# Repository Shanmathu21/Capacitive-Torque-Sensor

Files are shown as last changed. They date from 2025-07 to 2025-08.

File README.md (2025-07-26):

# Capacitive Torque Sensor Project

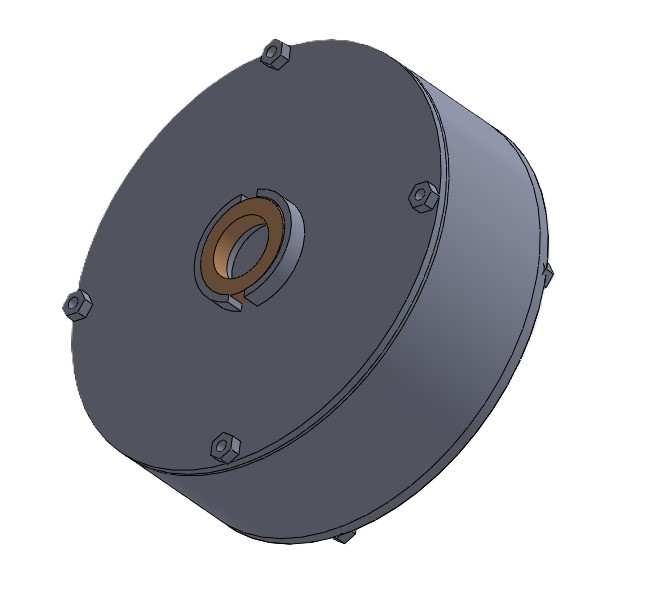
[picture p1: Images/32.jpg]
Product Overview


Welcome to the official repository for our **Capacitive Torque Sensor** – a novel torque sensing solution designed for precision, compactness, and cost-effectiveness. This repository contains all design files, documentation, and resources used in the development of our sensor system.

## 📂 What’s Inside?

This repo includes:

- ✅ **CAD Designs** (SolidWorks): 3D models for the sensor structure.
- ✅ **PCB Schematics** (Altium): Custom-designed electronics for sensing.
- ✅ **Firmware Code**: Interface microcontroller with CDC and output handler.
- ✅ **Documentation**:
  - Full Design Report
  - Production & Assembly Guidelines
  - User Manual
- ✅ **Images**: CAD visualizations, PCB renders, and actual prototype internals.

---

## 🛠️ Project Summary

Our system measures torque through **capacitive sensing technology**, leveraging the deformation of sensor plates to detect torque-induced changes in capacitance.

**Core Components:**

- **Sensor Design**: Custom plate layout for deflection measurement.
- **Capacitance-to-Digital Converter**: Using *PCAP04 CDC* for accurate sensing.
- **Microcontroller Interface**: *ATmega16U4/32U4* for data processing and USB communication.
- **Visualization**: Real-time torque output via display and PC interface.
- **Mechanical Housing**: Designed with precision for durability and alignment.

---

## 👥 Team & Collaboration

This project was accomplished by a passionate group of **8 dedicated undergraduate engineers** from the University of Moratuwa. Over weeks of brainstorming, prototyping, testing, and redesigning, we gave our full effort to bring this innovation to life.

---

## 📸 Highlights from the Build

### 1. Actual Final Product
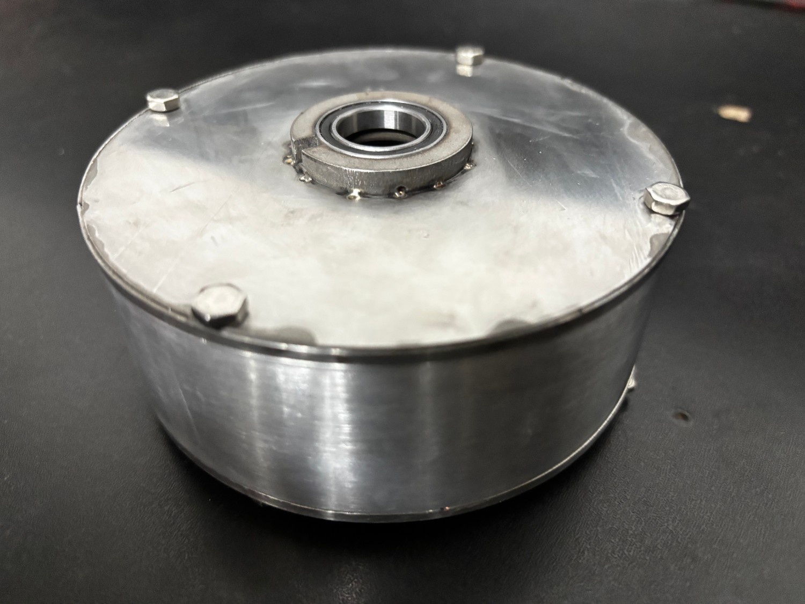
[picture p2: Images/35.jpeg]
CAD Design


### 2. Custom PCB
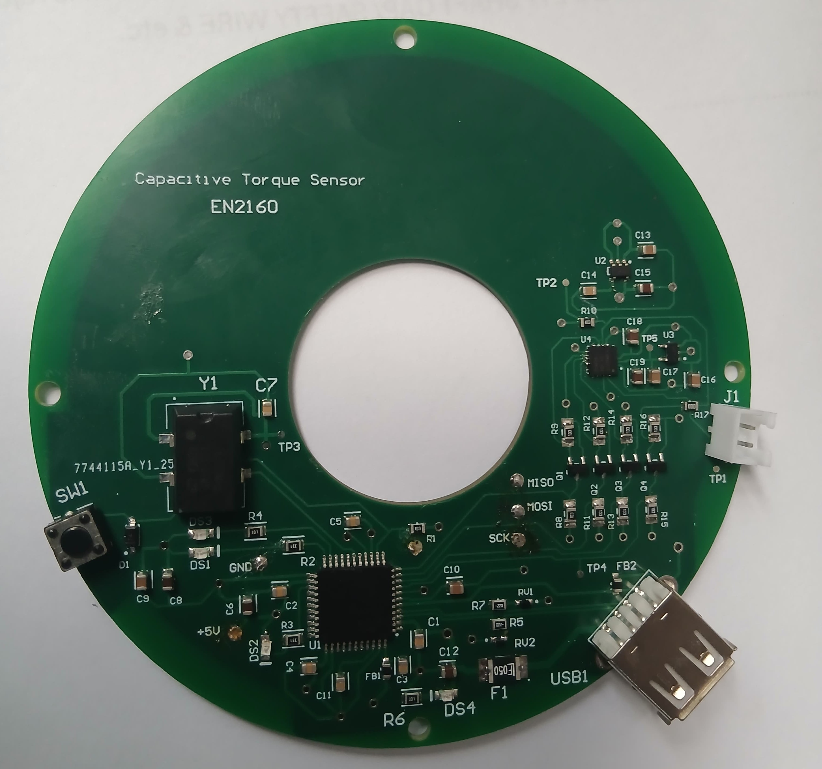
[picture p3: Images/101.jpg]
PCB Layout


### 3. Internal View of Sensor
Internal View

### 4. Exploded View
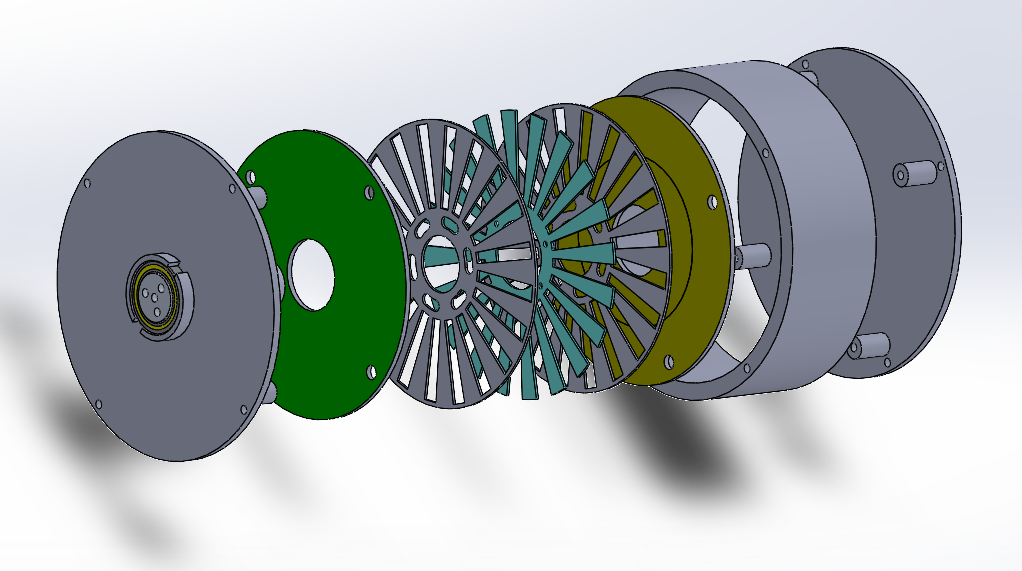
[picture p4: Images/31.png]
Exploded View


---

## 📌 Final Note

While we couldn't get a fully working sensor in the end, we achieved nearly **80% of our goal**. Our team poured countless hours into designing, simulating, assembling, coding, debugging, and refining this sensor. The journey taught us more than just engineering—it taught us perseverance, teamwork, and the power of iterative improvement.

> “Hard work doesn't always guarantee success, but it always guarantees growth.”

---

🧠 Thank you for checking out our work. Feedback and suggestions are warmly welcome!

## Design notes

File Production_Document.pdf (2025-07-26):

# Production Document

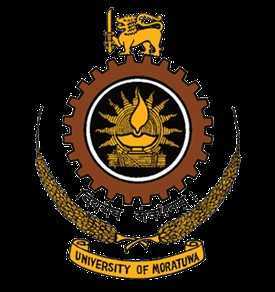
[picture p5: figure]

### Department of Electronic and Telecommunication Engineering

### University of Moratuwa

# Capacitive Torque Sensor

## Group Members:

## De Zoysa.A.S.I - 220106D Dayananthan.T - 220096T Mathujan.S - 220389U Pirathishanth.A - 220480P Jeyasekara.S.P.R - 220257N Sulojan.R - 220626V Ananthakumar.T - 220029T Ahilakumaran.T - 220017F

## 1 Objective

The objective of this production report is to document the development, manufacturing process, and performance evaluation of the Capacitive Torque Sensor. This report aims to provide a comprehensive overview of the sensor’s design, production stages, quality control measures, and testing results to ensure it meets the required specifications for accuracy, sensitivity, and durability. Additionally, this report serves as a reference for stakeholders, facilitating future improvements, scalability, and compliance with industry standards. By detailing key challenges, solutions, and production efficiencies, this document supports continuous optimization and successful deployment of the torque sensor in its intended applications.

## 2 System Overview

### 2.1 Working Principle

When torque (τ ) is applied to the shaft, it induces a proportional angular deflection (θ) along the axis, governed by:

τ = G · J ·

θ
L

(1)

where G is the shear modulus, J the polar moment of inertia, and L the shaft length.

### 2.1.1 Capacitance Variation Mechanism

The angular deflection alters the overlapping area (A) between two parallel conductive plates separated by a dielectric (e.g., polyimide film). The capacitance (C) is given by:

C = ε0εr

A
d

(2)

where ε0 is vacuum permittivity, εr the dielectric constant, and d the plate separation. Area Modulation: Radial plate geometry maximizes sensitivity to angular displacement.

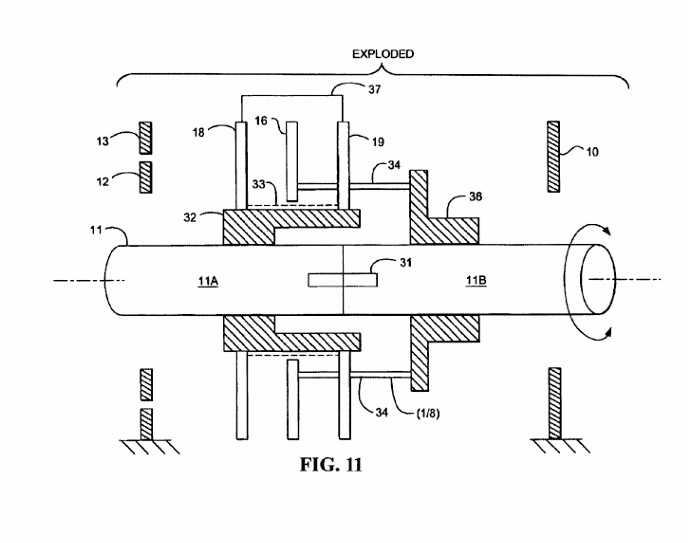
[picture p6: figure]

Figure 1: Internal Arrangement of the Sensor

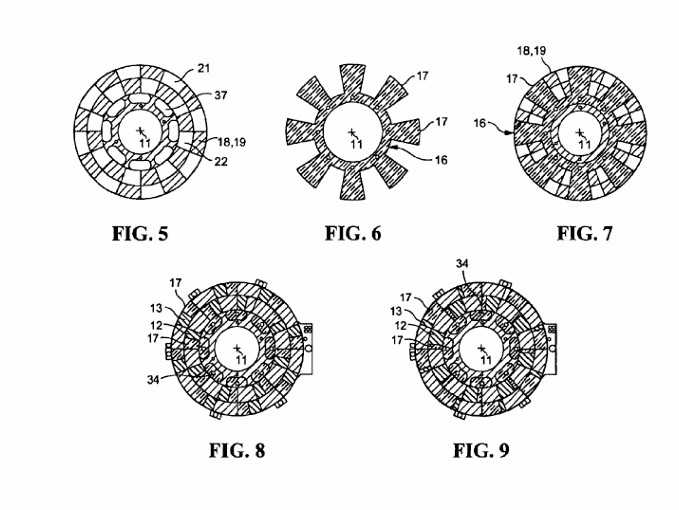
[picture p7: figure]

Figure 2: Area modulation in the capacitance measurement

### 2.1.2 Signal Processing Chain

- Capacitance-to-Digital Converter (PCAP04):

– 24-bit resolution for ±0.1 fF sensitivity

– Integrated temperature compensation

– SPI interface for microcontroller communication

- Microcontroller (ATmega32U):

– Linearizes data using polynomial calibration curves

– Outputs data via USB at 1 kSPS

### 2.2 Block Diagram

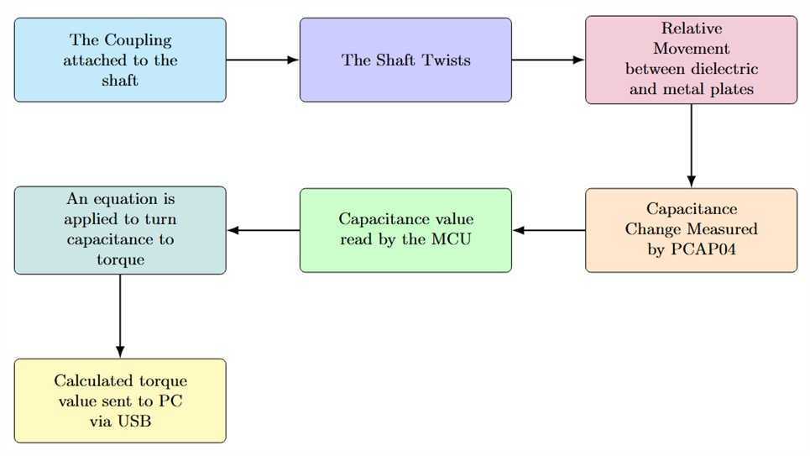
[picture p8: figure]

Figure 3: Block diagram of the system

## 3 Mechanical Design

The mechanical design of the capacitive torque sensor consists of two primary components: the enclosure, which provides robust protection and structural integrity, and the internal structure, which houses the sensitive capacitive elements and ensures precise torque measurement.

### 3.1 Enclosure Overview

The enclosure is constructed from anodized aluminum to provide corrosion resistance and electromagnetic shielding. Its design includes mounting flanges for secure attachment to rotating shafts, and it houses the capacitive sensing elements while maintaining environmental protection.

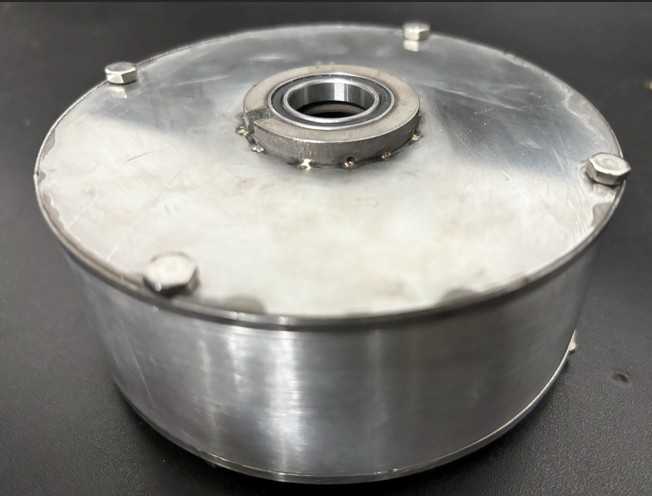
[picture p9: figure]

Figure 4: Enclosure of the Sensor

### 3.1.1 Parts of the enclosure

The enclosure consists of a middle body, 2 outer lids and 2 bearings.

### 3.2 Internal structure Overview

Internal mechanism of the sensor consists of a shaft,2 metal disks, 1 dielectric disk, holders of the disks.

### 3.2.1 Assembly of Internals

1. Begin by attaching the first metal disk to the holder.
2. Place the dielectric disk over the first metal disk, ensuring proper alignment.

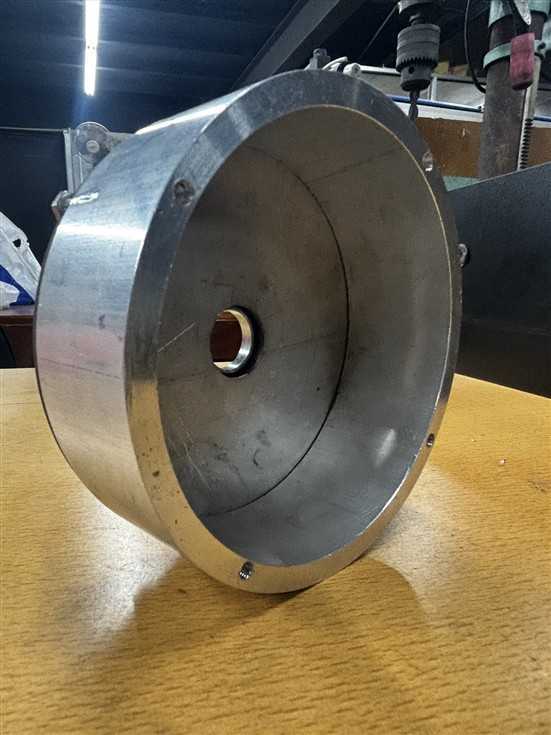
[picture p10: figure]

Figure 5: Middle part of the enclosure made of aluminium

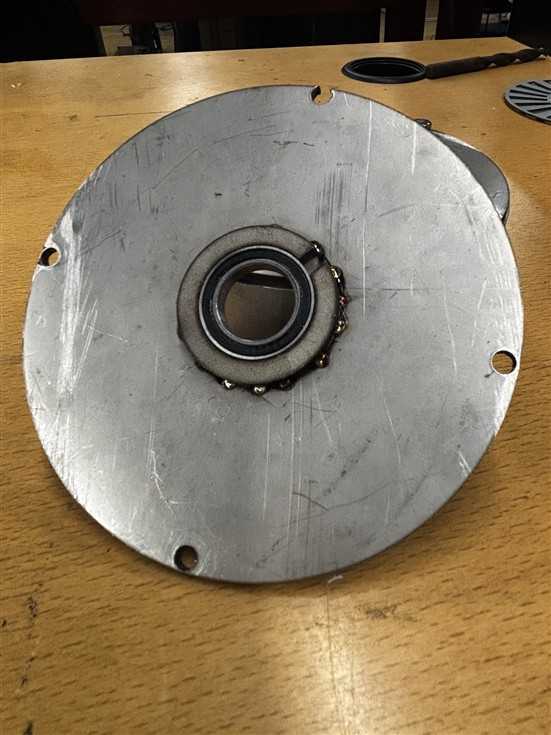
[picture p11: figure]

Figure 6: Outer lids of the sensor made of steel.

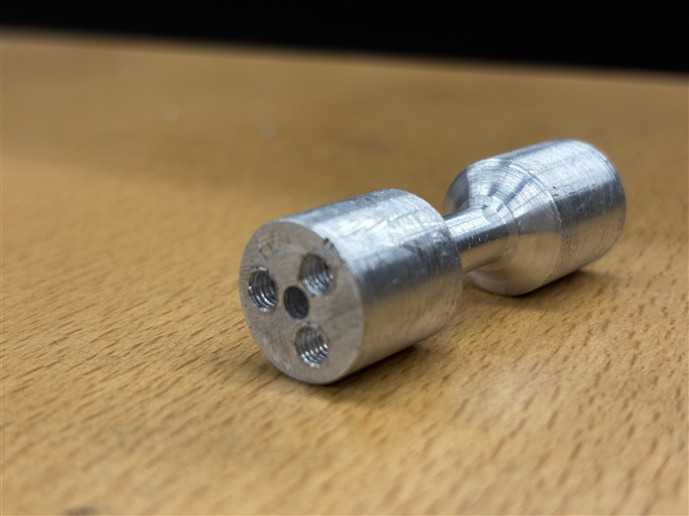
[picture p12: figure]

Figure 7: Aluminium shaft machined using a lathe.

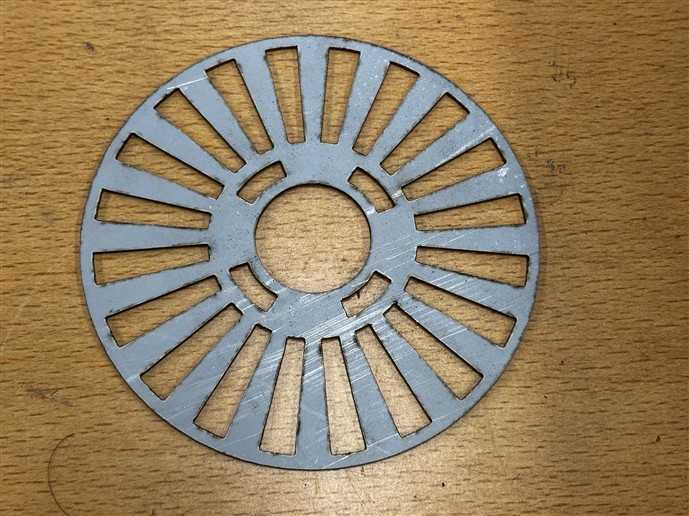
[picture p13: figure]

Figure 8: Metal disks made of nickel-coated steel, cut using CNC machining

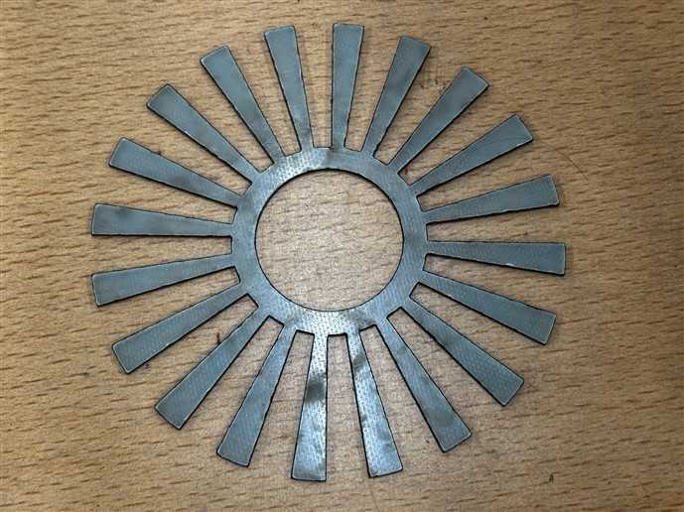
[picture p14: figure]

Figure 9: Dielectric disk cut using laser cutting.

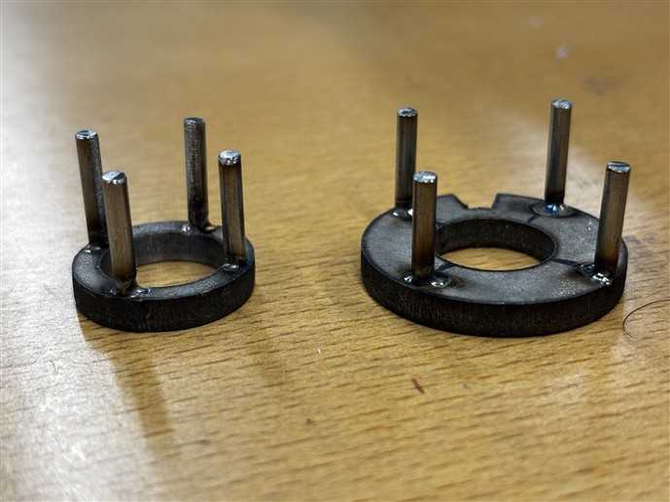
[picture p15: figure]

Figure 10: Holders that connect metal and dielectric disks to the shaft.

3. Attach the second metal disk on top of the dielectric disk using the same holder.
4. Secure the assembled holder to the shaft.
5. assemble the dielectric with the second holder.
6. Attach the second holder to the shaft.
7. Finally, mount the shaft onto the bearings to complete the assembly.

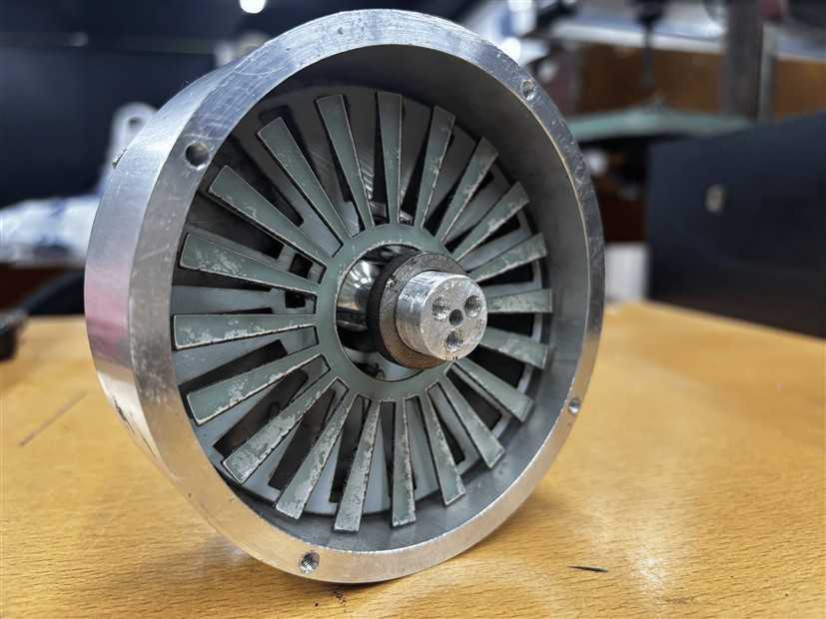
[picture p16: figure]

Figure 11: Complete internal assembly.

## 4 Schematic Circuit Design

### 4.1 MCU Circuit

– Core Components:
∗ ATmega32U4 microcontroller
∗ Key functions:
- Reads capacitance via SPI
- Computes torque using calibration equation
- Manages USB communication

– Power Management:
∗ 5x VCC pins with decoupling capacitors
∗ AVCC pin filtered via ferrite bead

– Clock: ECS-8FMX-160-TR 16MHz oscillator for USB timing

– UI: Reset button, 3x LEDs (USB/SPI/status)

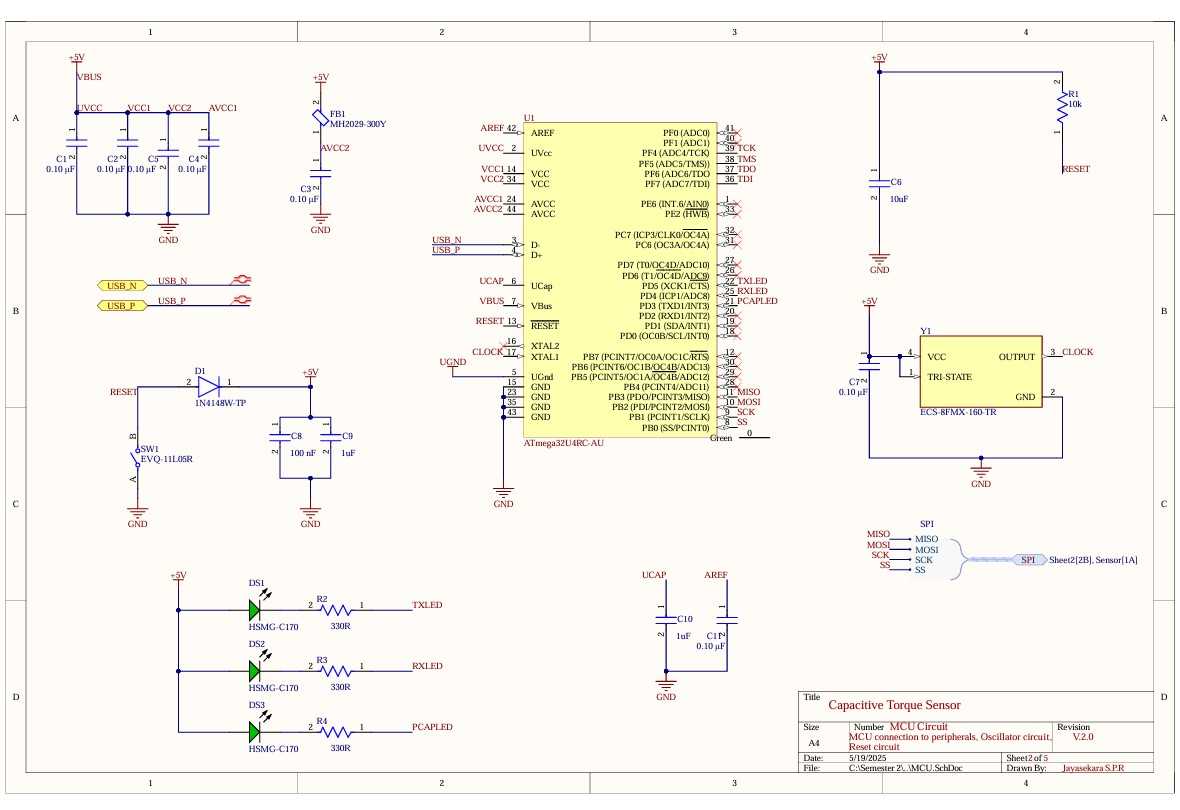
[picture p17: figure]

Figure 12: MCU Schematic

### 4.2 USB Circuit

– Provides data transmission and power supply (+5V via VBUS).

– ESD Protection:
∗ +D/-D lines connected to ground through varistors.

– Grounding:
∗ USB ground (UGND) and main ground linked via ferrite bead for:
- High-frequency noise filtering
- Prevention of ground loops

– Power Line Protection:
∗ Resettable fuse for overcurrent protection ∗ Capacitor C12 for ripple smoothing
∗ LED DS4 as power indicator

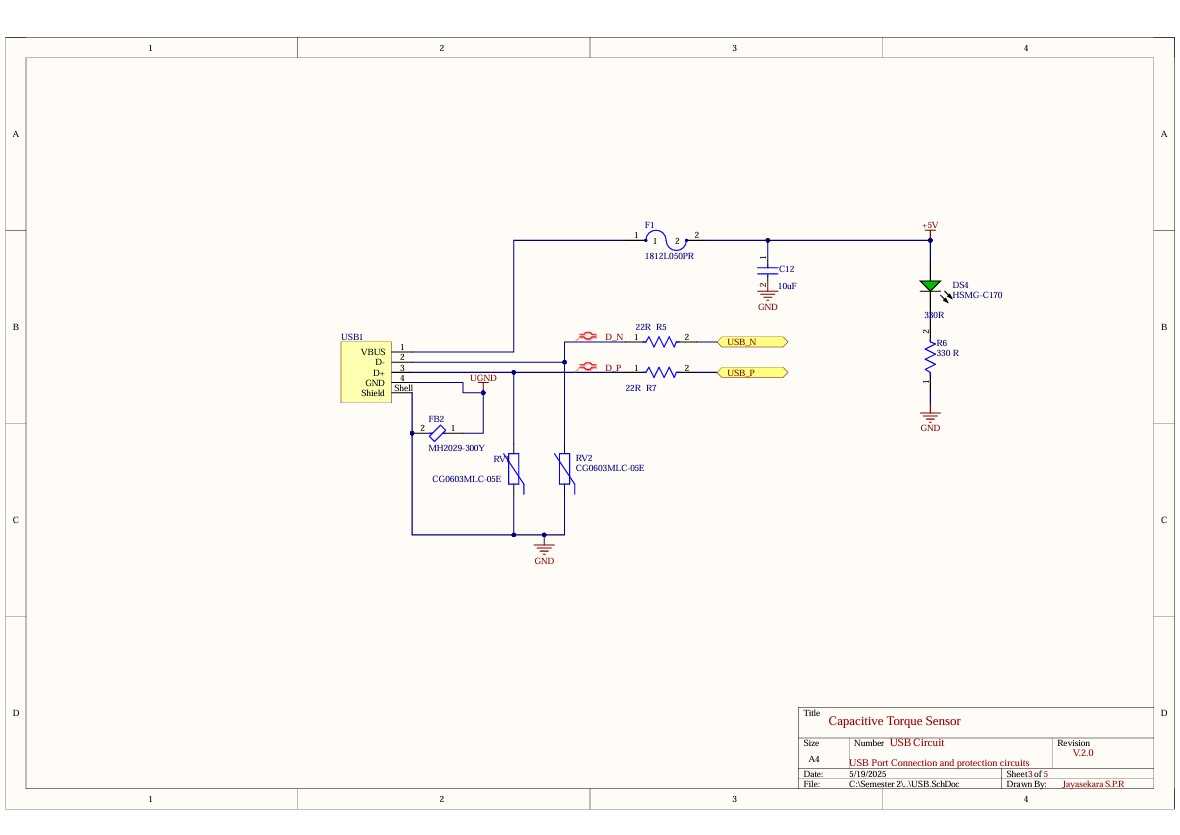
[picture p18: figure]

Figure 13: USB Schematic

### 4.3 Power Circuit

– Generates regulated voltages:
∗ +3.3V and +1.8V for PCAP04 CDC

– Design Features:
∗ Enable pins tied to VCC for continuous operation ∗ Input/output capacitors for:
- High-frequency noise filtering
- Ripple reduction

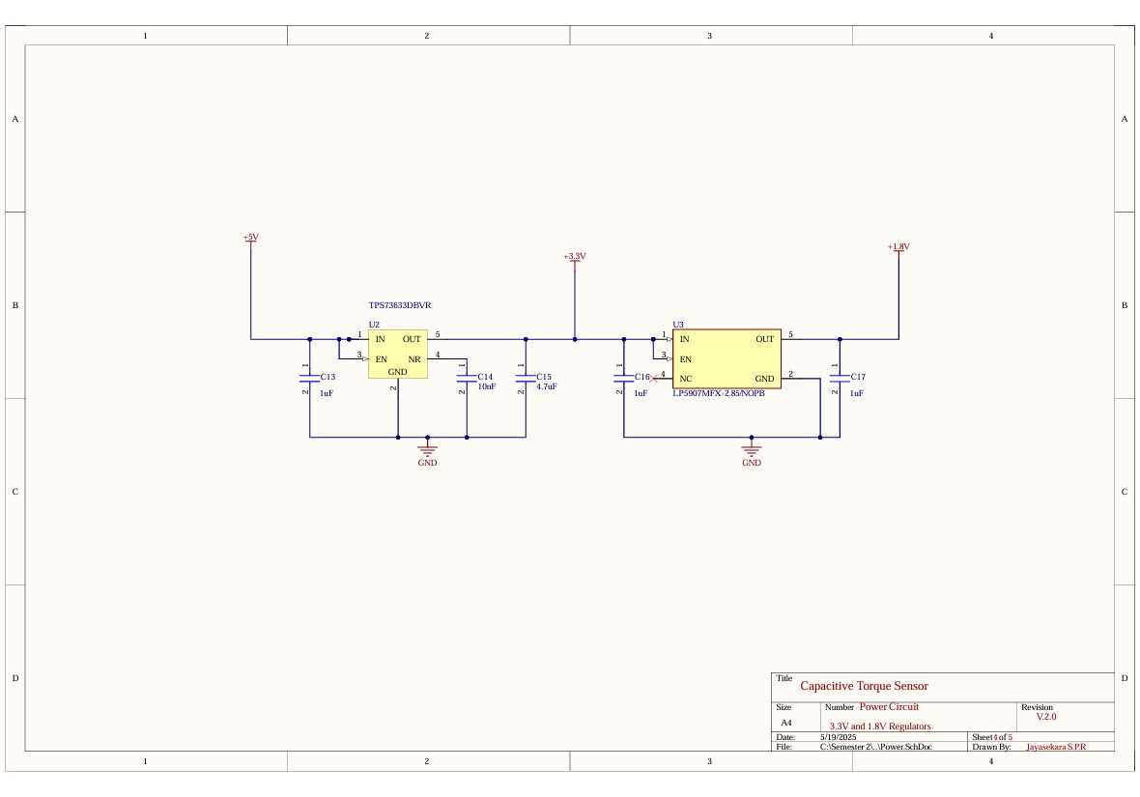
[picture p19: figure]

Figure 14: Power Supply Schematic

### 4.4 Sensor (CDC) Circuit

– Capacitance-to-Digital Converter (PCAP04):
∗ Powered by +3.3V (digital) and +1.8V (analog)
∗ PC1 pin connected to sensor plates via 2-wire JST connector ∗ Operates in differential capacitance mode
∗ SPI communication with MCU

– MOSFET Level Shifters:
∗ Converts MCU’s +5V signals to +3.3V for CDC
∗ Replaced TXB0104PWR IC due to low drive current ∗ Used for SPI lines (SCK, MOSI, MISO, CS)

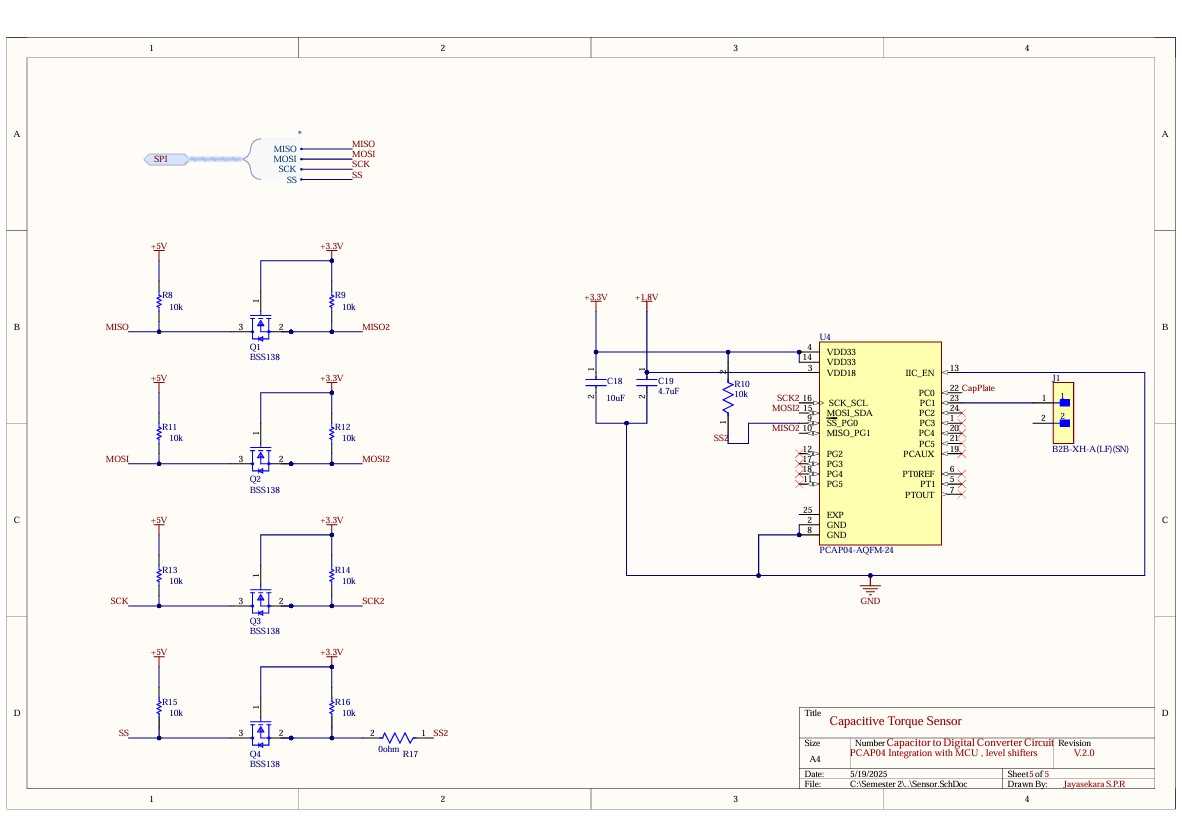
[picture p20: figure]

Figure 15: CDC Sensor Schematic

## 5 Electronics and PCB

The sensor assembly comprises two PCB boards, One board contains all the components and signal routing, while the other is a simple single-sided board with a solid copper plane only one side, serving as a conductive plate of the capacitor .

### 5.1 PCB Overview

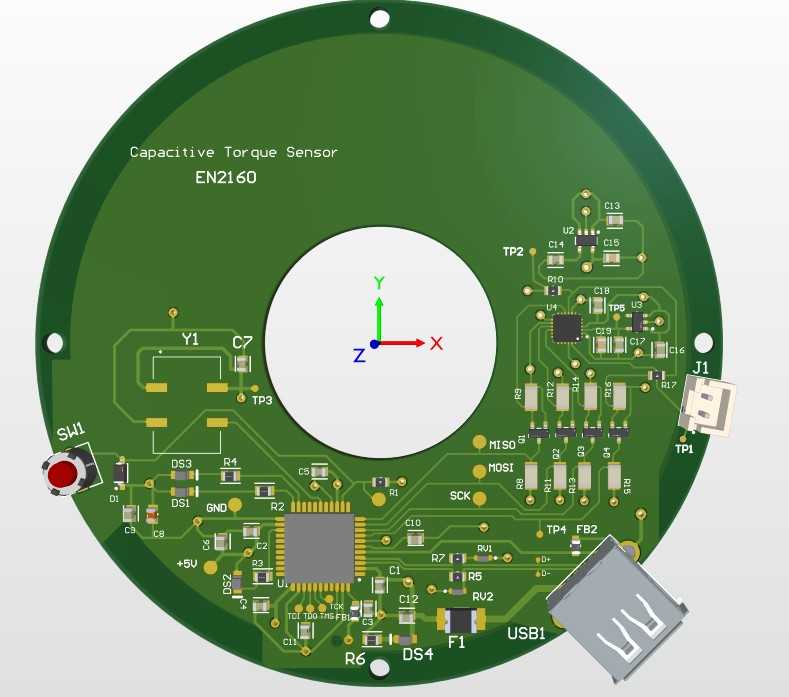
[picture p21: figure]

Figure 16: PCB with components.

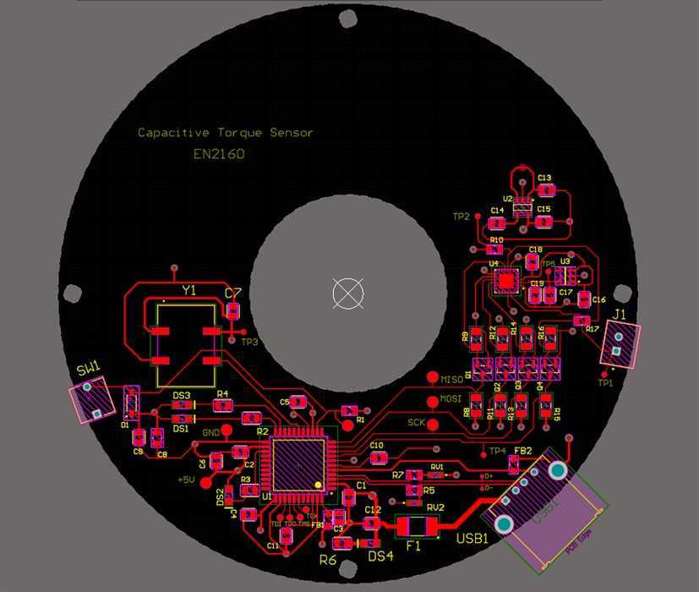
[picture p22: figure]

Figure 17: Top Layer of the PCB

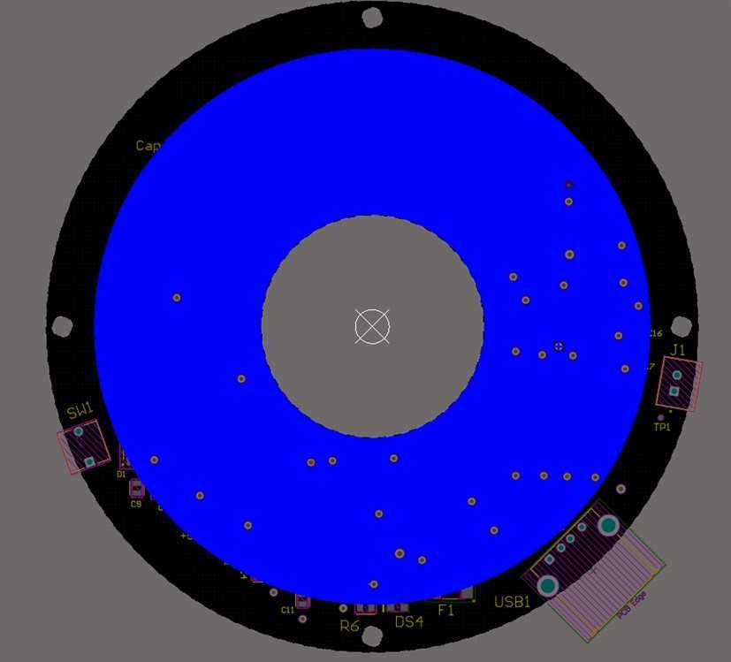
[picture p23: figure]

Figure 18: Bottom Layer of the PCB

### 5.2 Layer Stack-Up

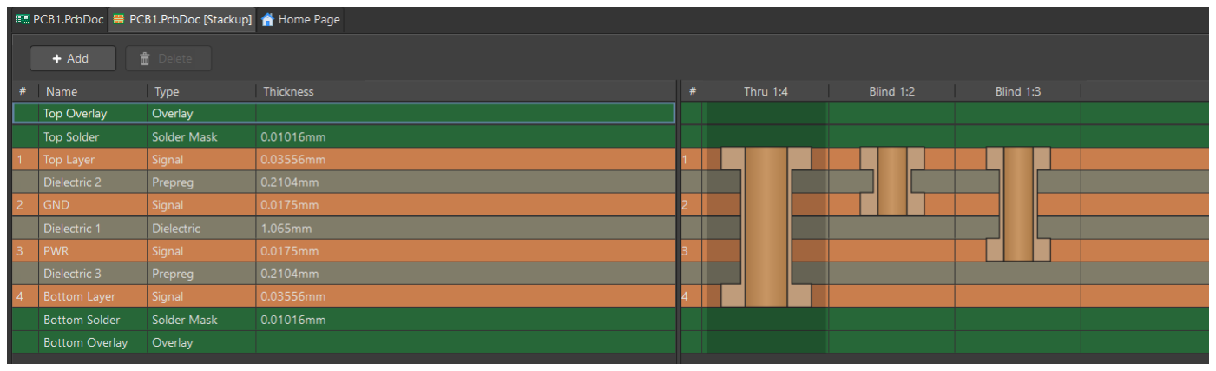
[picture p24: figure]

Figure 19: Layer Stack-Up of the PCB

As illustrated in Figure 19,The Printed Circuit Board (PCB) comprises a four-layer stack-up: the top and bottom layers are allocated for signal routing, while the inner layers are designated as follows: Inner Layer 1 serves as the ground plane, and Inner Layer 2 is dedicated to the power distribution network (3.3V and 5V).

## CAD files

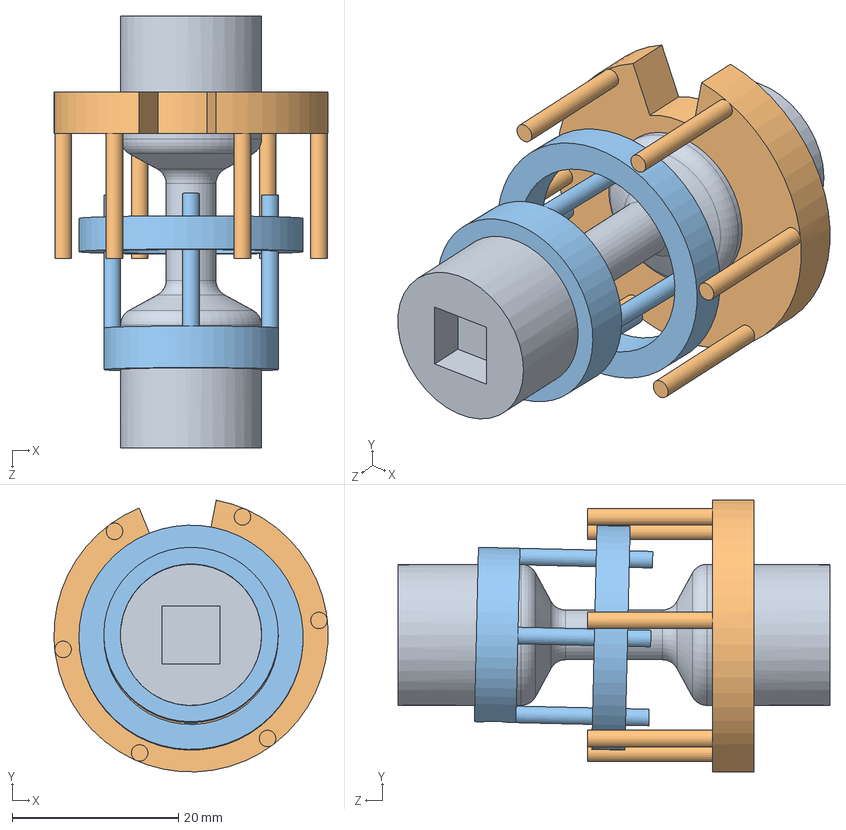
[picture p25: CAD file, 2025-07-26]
CAD Design (Solidworks)/Internal_assembly.SLDASM
33.0 x 32.7 x 52.0 mm
circle slot
dielectricholder
metalholder

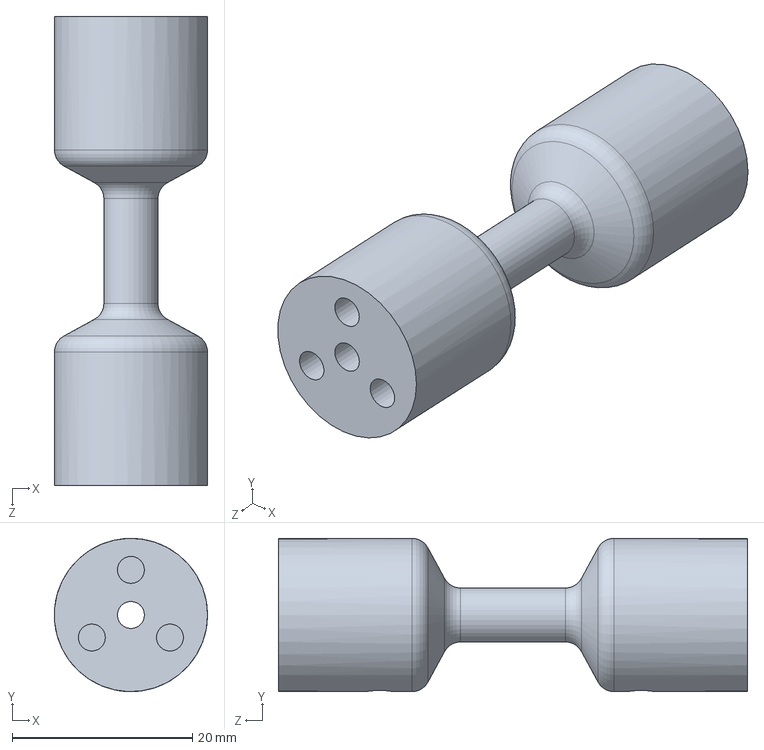
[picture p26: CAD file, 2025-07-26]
CAD Design (Solidworks)/Circle_slot.SLDPRT
17.0 x 17.0 x 52.0 mm

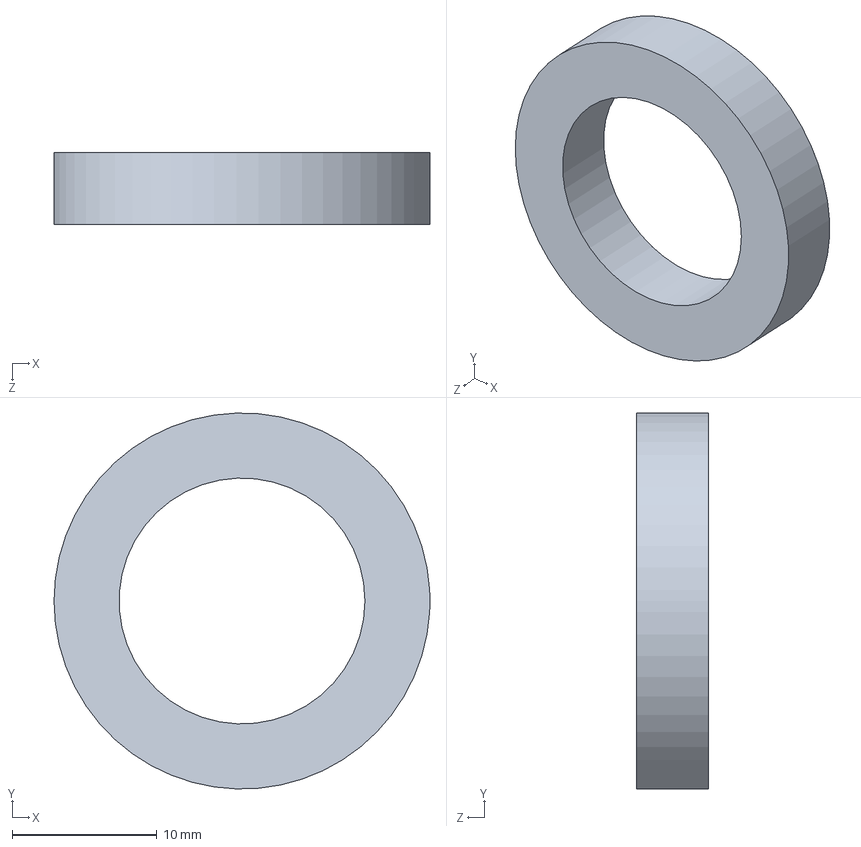
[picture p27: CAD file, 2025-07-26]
CAD Design (Solidworks)/Bearing.SLDPRT
26.0 x 26.0 x 5.00 mm

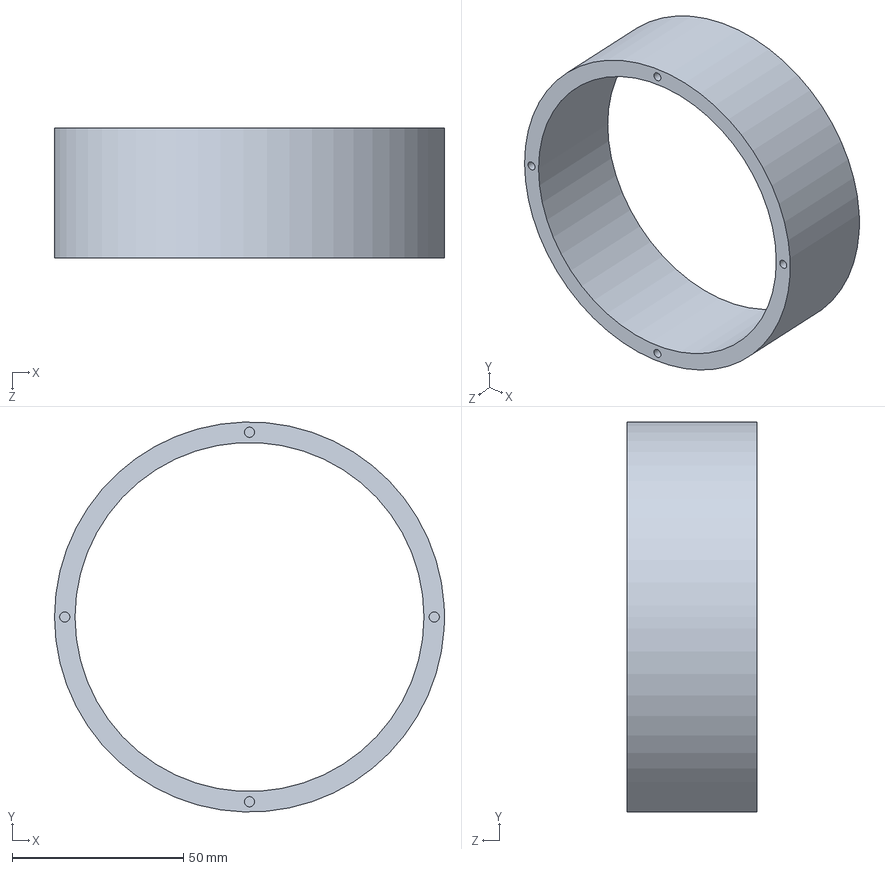
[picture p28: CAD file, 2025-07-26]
CAD Design (Solidworks)/Ring_outer_enclosure.SLDPRT
114.0 x 113.9 x 38.0 mm

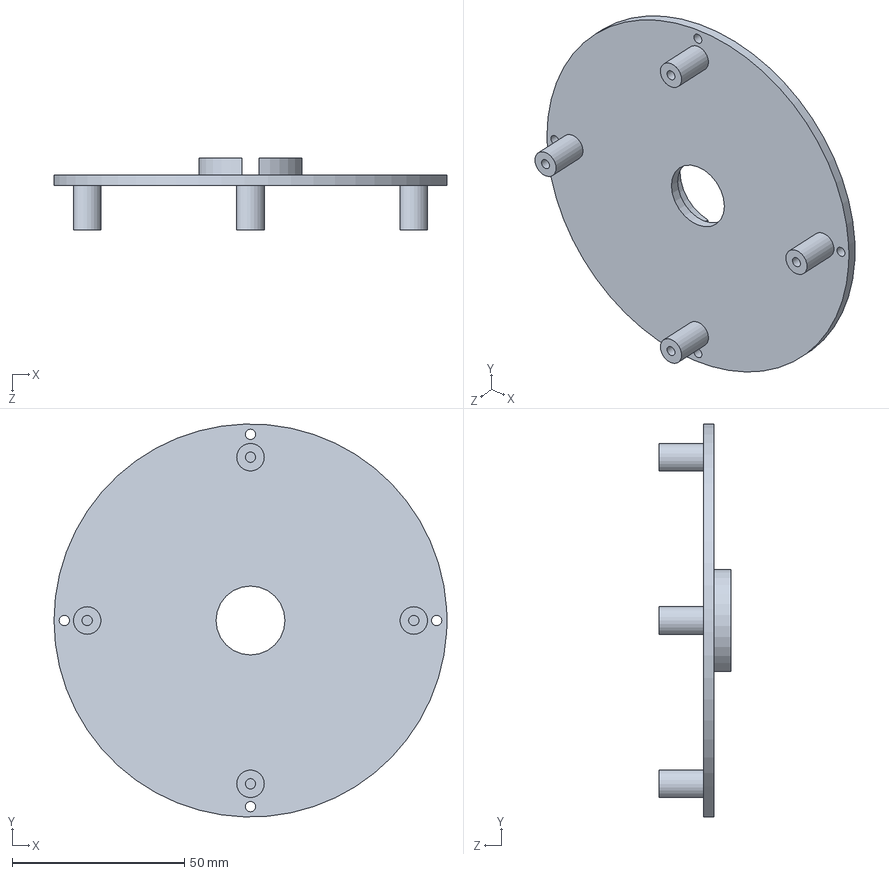
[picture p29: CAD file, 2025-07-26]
CAD Design (Solidworks)/Flat_lids.SLDPRT
114.0 x 113.9 x 21.0 mm

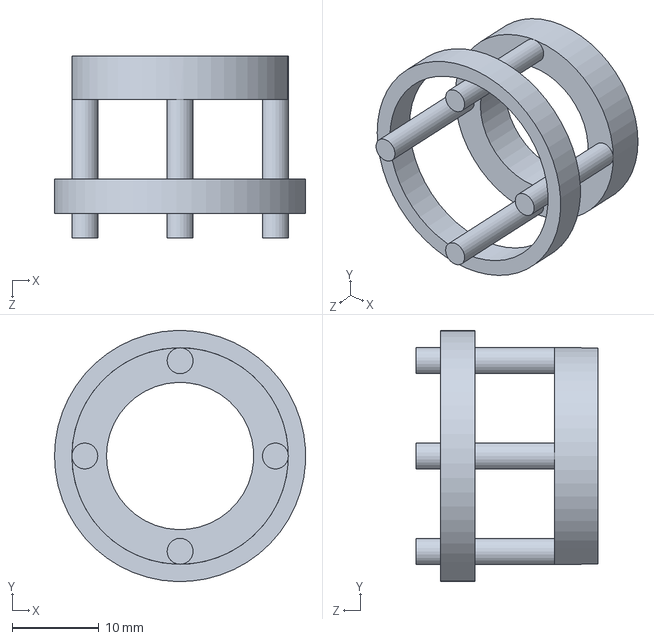
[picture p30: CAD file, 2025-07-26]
CAD Design (Solidworks)/Metal_holder.SLDPRT
29.0 x 29.0 x 21.0 mm

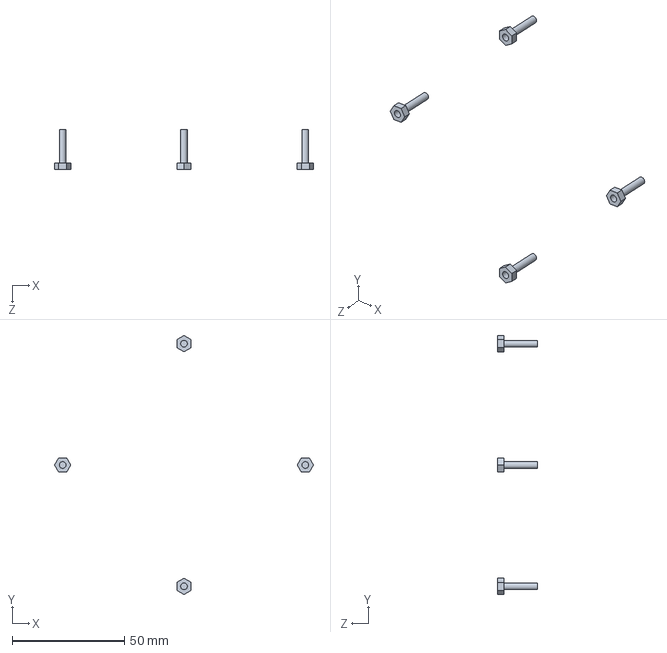
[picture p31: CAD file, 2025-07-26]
CAD Design (Solidworks)/Screws.SLDPRT
115.3 x 115.3 x 18.0 mm

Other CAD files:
CAD Design (Solidworks)/Metal_disk.SLDPRT
CAD Design (Solidworks)/Dielectric_disk.SLDPRT
CAD Design (Solidworks)/Dielectric_holder.SLDPRT

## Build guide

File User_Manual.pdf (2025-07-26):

# Capacitive Torque Sensor

# USER MANUAL

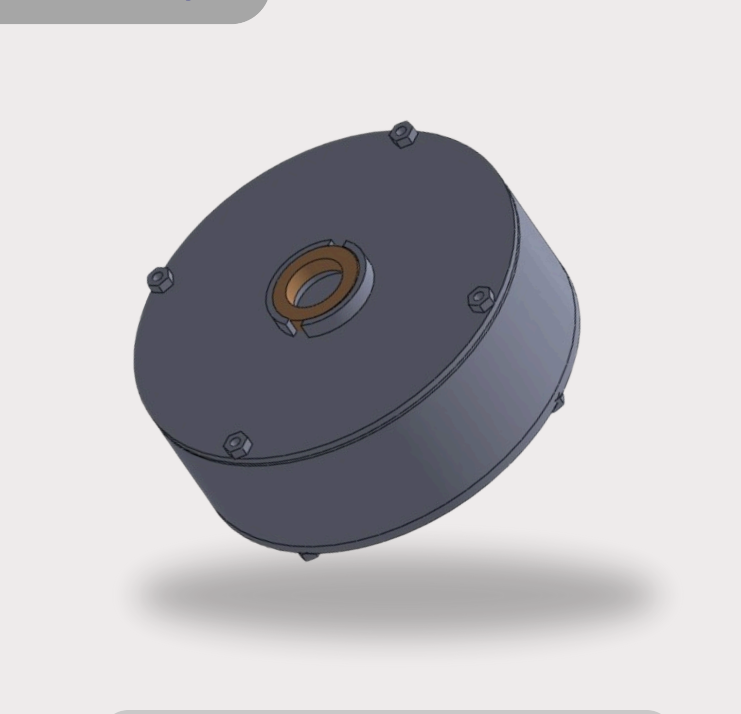
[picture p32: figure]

### By :- Team Capacitive Torque Sensor

## 01. Introduction

## 02. Getting started

## 03. Operating Instructions

## 04. Maintenance

# Table of Contents

1.1 Product Overview |
1.2 Product Packaging |
1.3 Product Specifications |
1.4 Theory of operation |
2.1 Unpacking |
2.2 Prerequisites |
2.3 Installation |
3.2 Instructions & get familiar |
4.1 Preventive Maintenance |
4.2 Troubleshooting |
4.3 Cleaning |
4.4 Safety precautions |

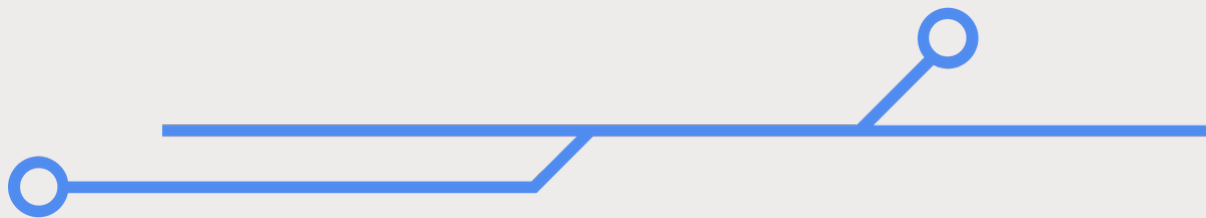
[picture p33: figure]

## 01. Introduction

The Capacitive Torque Sensor is a high-precision, compact sensing device specifically designed to measure torque in rotating systems with outstanding accuracy and reliability. Utilizing advanced differential capacitive sensing technology coupled with a high-resolution digital conversion interface, the sensor delivers exceptional sensitivity and stability across a wide range of applications.

Engineered for user convenience, this sensor features a compact plug-and-play design, requiring no external signal conditioning or complex setup procedures. Simply connect the device via a standard USB cable to a PC or data acquisition system to instantly begin capturing real-time torque measurements. The integrated interface allows for seamless communication with monitoring software, enabling data visualization, logging, and analysis with minimal effort.

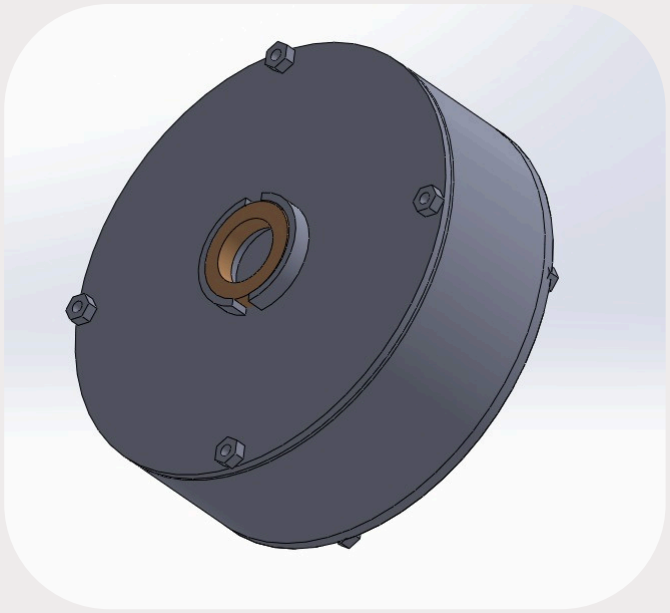
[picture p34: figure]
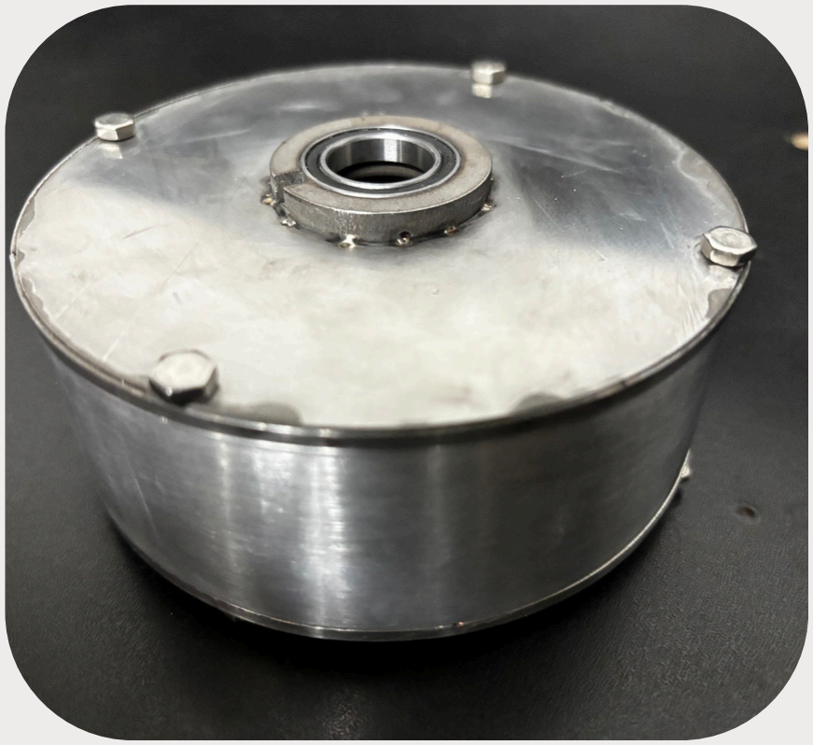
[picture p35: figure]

CAD Design | Actual Product

### 1.1 Product Overview

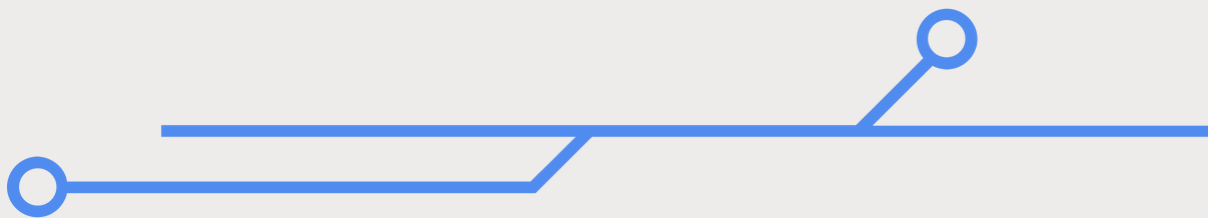
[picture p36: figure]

### 1.2 Product Packaging

The product is securely packed to ensure safe transport and easy setup. The package includes the following components:

1.Sensor with shaft – The main sensor device equipped with a USB interface for data communication.
2.USB 2.0 Cable (USB-A to USB-B) – Standard USB 2.0 cable for connecting the sensor to a computer or host device.
3.2 Couplers with 4 Screws – Mechanical couplers designed for easy mounting of shaft connectors and external shaft, each accompanied by 2 screws (total of 4). 4.2 Coupler Connectors with 6 Screws – Interface connectors for mechanical integration, each provided with 3 screws (total of 6).

1.
2.

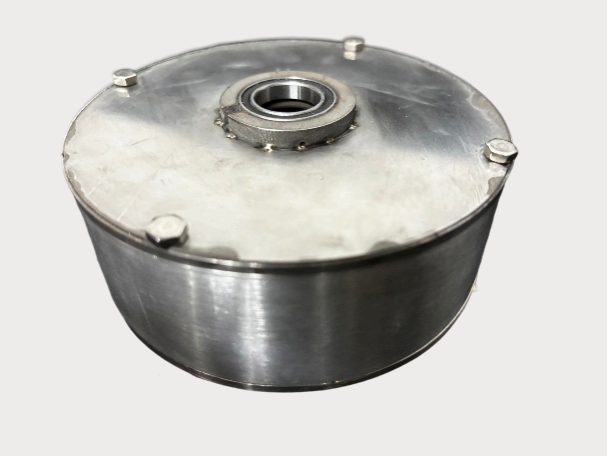
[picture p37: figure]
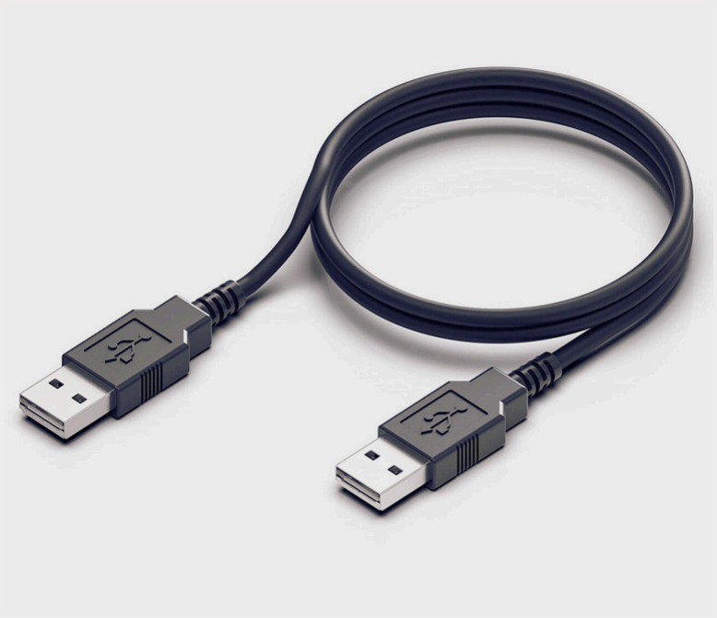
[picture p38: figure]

3. 4.

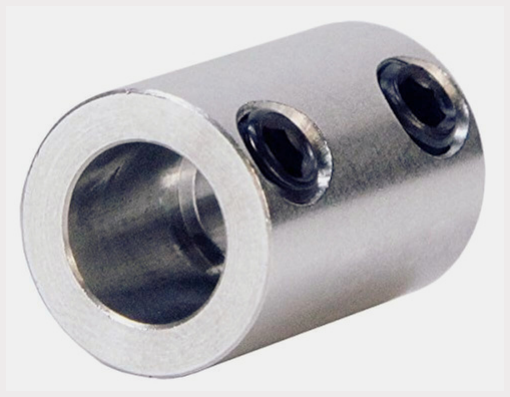
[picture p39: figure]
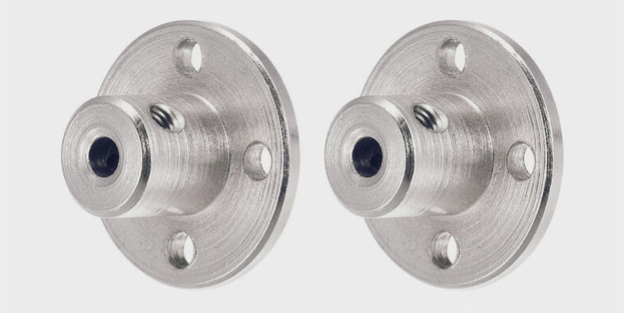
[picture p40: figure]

Parameter | Value
Shaft Material | Aluminium Alloy 6061-T6
Shaft Dimensions | 1.7 cm (ends), 0.6 cm (middle)
Operating Temperature | Up to 140°C
Weight | Approx. 500 g

### 1.3 Product Specifications

### 1.3.2 Technical specification

Parameter | Value
Sensing Principle | Differential Capacitive Sensing
Capacitance Range | ±50 pF
Capacitance Resolution | 156 aF at 1 kHz (PCAP04)
Torque Range | 0 – 1 Nm
Measurable Capacitance Change | ~357.4 fF at 1 Nm
Sampling Rate | 1000 samples/second
Microcontroller | ATmega32U4, 16 MHz
Flash Memory | 32 KB
RAM | 2.5 KB
USB Support | Native USB 2.0

### 1.3.1 General Information

Specification | Min | Max | Typical | Unit
Operating voltage | 3.3 | 5 | 3.3 | V
USB Operating voltage | 4.75 | 5.25 | 5 | V
USB Current Draw | - | 25 | 10 | mA
Logic Input Voltage | 2.97 | 3.63 | 3.3 | V
Logic Input Current | 10 | 100 | 50 | µA

### 1.3.3 Electrical Specifications

### 1.3.4 Mechanical Specifications

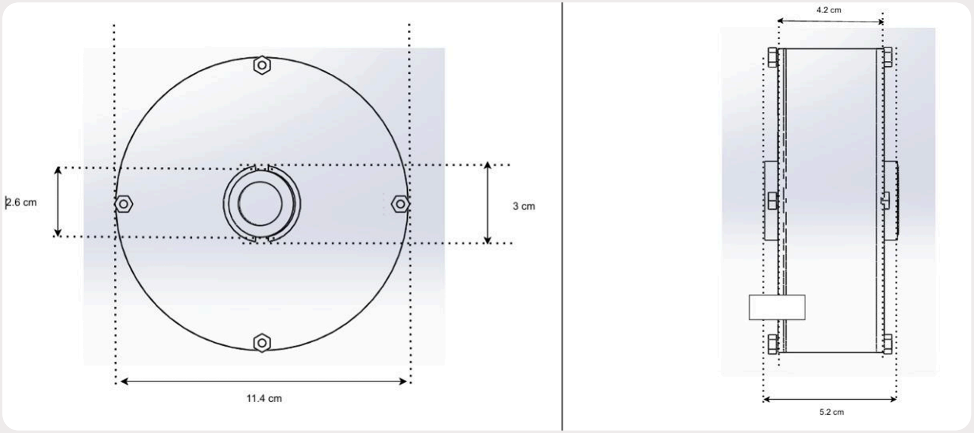
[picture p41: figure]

### 1.4 Theory of Operation

The sensor measures torque by detecting changes in capacitance between differential plates. This happens due to the relative movement of the metal and dielectric plates mounted on the shaft. These changes are converted into digital data using a PCAP04 CDC chip and that result turned to torque values by substituting to an equation. The torque value is then transmitted to computer through USB communication.

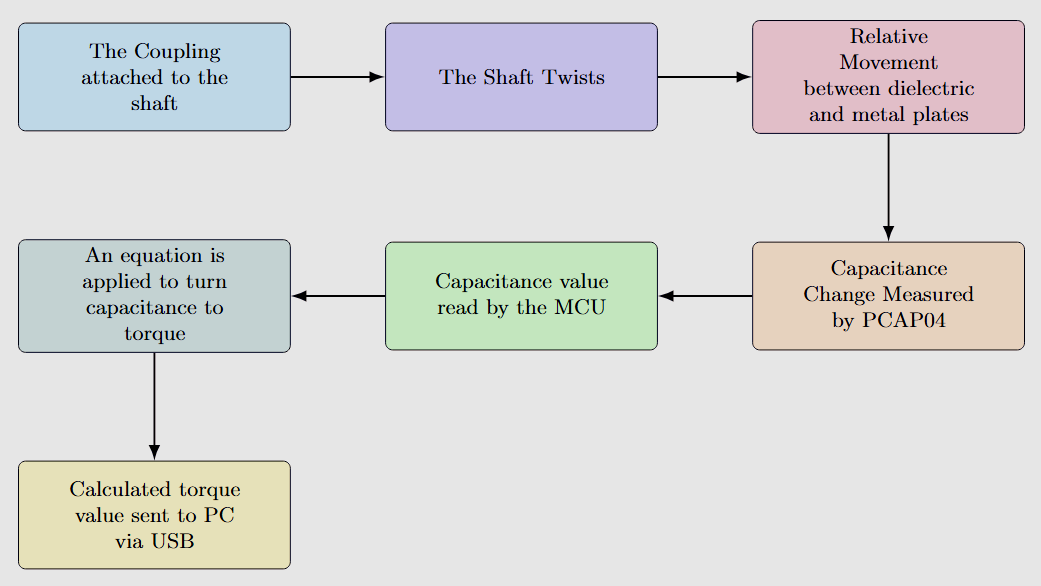
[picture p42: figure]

### 2.1 Unpacking

## 02. Getting Started

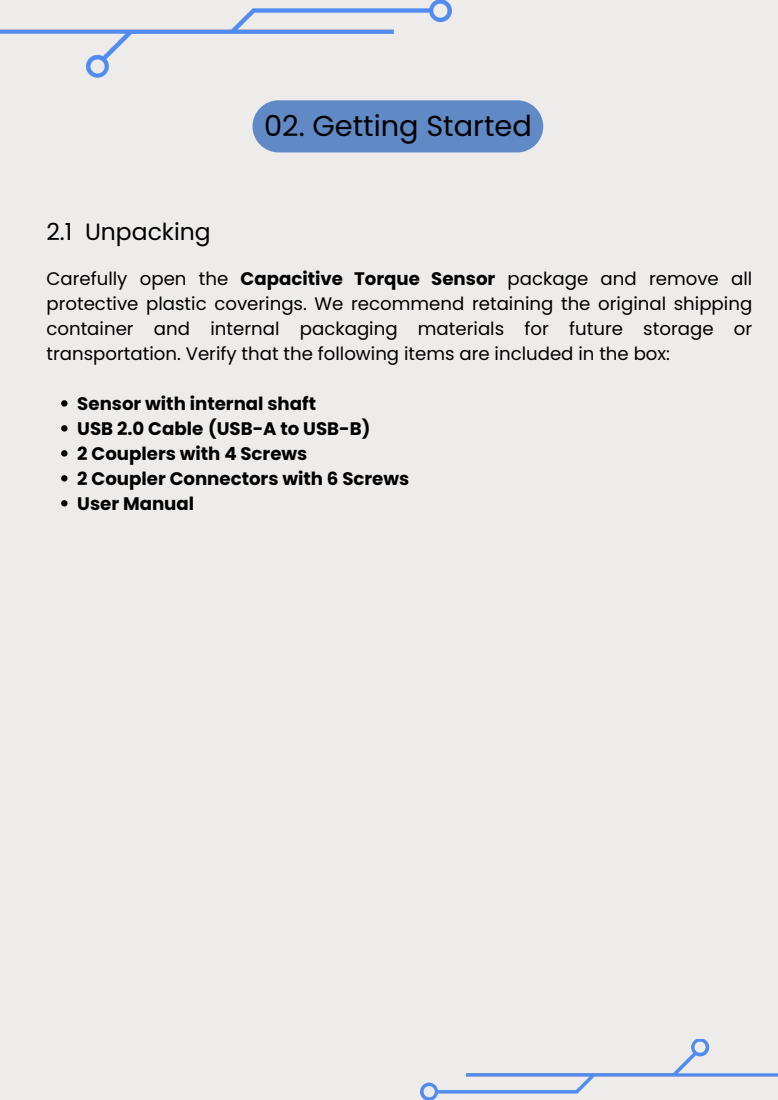
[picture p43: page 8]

Carefully open the Capacitive Torque Sensor package and remove all
protective plastic coverings. We recommend retaining the original shipping
container and internal packaging materials for future storage or
transportation. Verify that the following items are included in the box:

Sensor with internal shaft
USB 2.0 Cable (USB-A to USB-B)
2 Couplers with 4 Screws
2 Coupler Connectors with 6 Screws
User Manual

### 2.2 Prerequisites

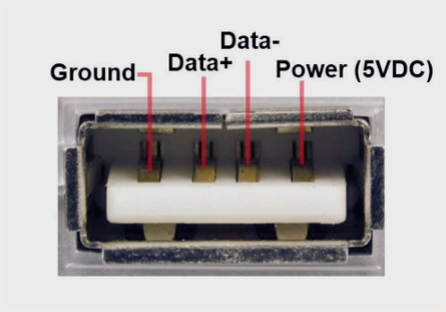
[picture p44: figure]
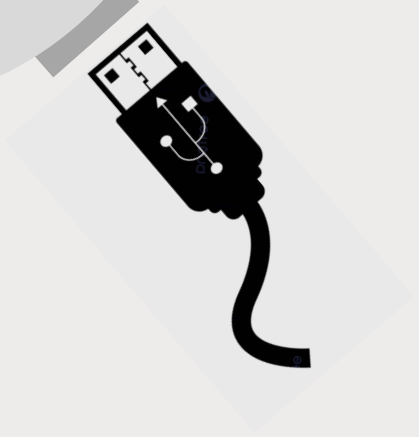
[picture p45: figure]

### USB Connection to the sensor

Manpower Required: One technician with basic electronics and mechanical knowledge.
Tools Required: Allen keys, USB cable, torque driver.
Materials Required: Mounting screws, coupler connector, alignment tools. Connection Diagram: USB-powered to Sensor by PC.

### 2.3 Installation

Step 1: Prepare the Setup

Clean the workspace.
Gather necessary tools (screwdrivers, Allen keys).
Ensure all components are available: sensor, screws, USB-B cable.

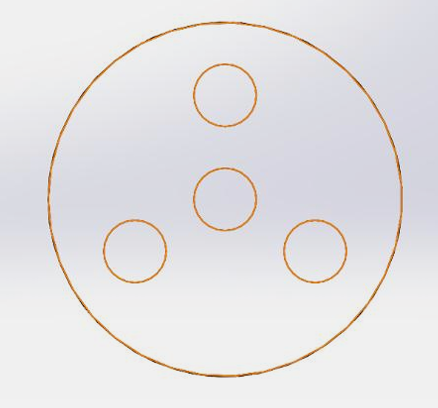
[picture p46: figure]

Step 2: Mount the Sensor Mechanically

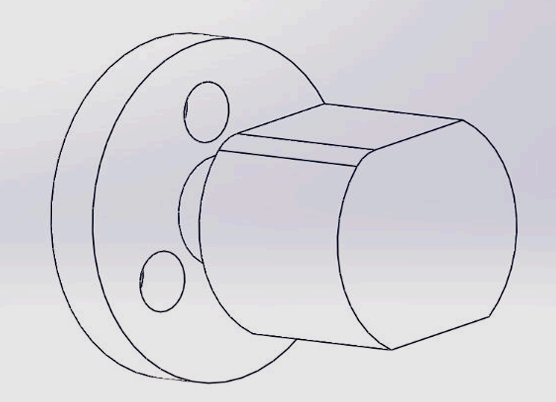
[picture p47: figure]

The coupler connector connects shaft to couplers of standard sizes.

Identify the input and output shafts.
Attach coupler connector of proper size to both: Select connectors matching the shaft diameter and secure them with set screws.
Attach the connectors to proper couplers: Ensure the connectors align with the coupler’s keyways or slots for a firm fit.
Attach one of the couplers to the input shaft which is connected to torque generator (Motor):
Attach the other coupler to the output shaft connecting the load.
Face of the shaft | The coupler connector

Use alignment tools to ensure no angular misalignment: Employ a laser alignment tool or dial indicator to confirm precise shaft alignment.

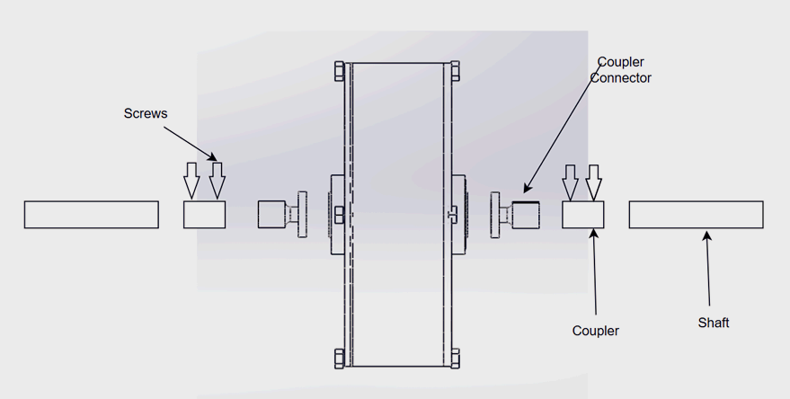
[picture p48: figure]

How sensor is connected to shafts via coupling

Step 3: Launch the Software

Open the torque sensor GUI software in your PC: Double-click the torque sensor GUI application icon on your desktop, or navigate to the installation directory (e.g., C:\Program Files\TorqueSensorGUI) and launch the executable file.
Ensure USB drivers are properly installed in sensor: Verify that the latest USB drivers for the torque sensor are installed on your PC. If not, download them from the manufacturer’s website and follow the installation wizard.
Confirm the system detects the sensor: In the GUI software, go to the “Device” or “Connection” menu and select “Detect Sensor.” Wait for the software to scan and display the sensor’s serial number or model details in the status window. If the sensor is not detected, disconnect and reconnect the USB cable, then retry the detection process.
Ensure the port number detect correctly: Check the software’s connection settings to confirm the correct COM port (e.g., COM3) or USB port is assigned to the sensor. If the port is incorrect, manually select the appropriate port from the dropdown menu based on the PC’s port assignment (visible in Device Manager).

## 03. Operating Instructions

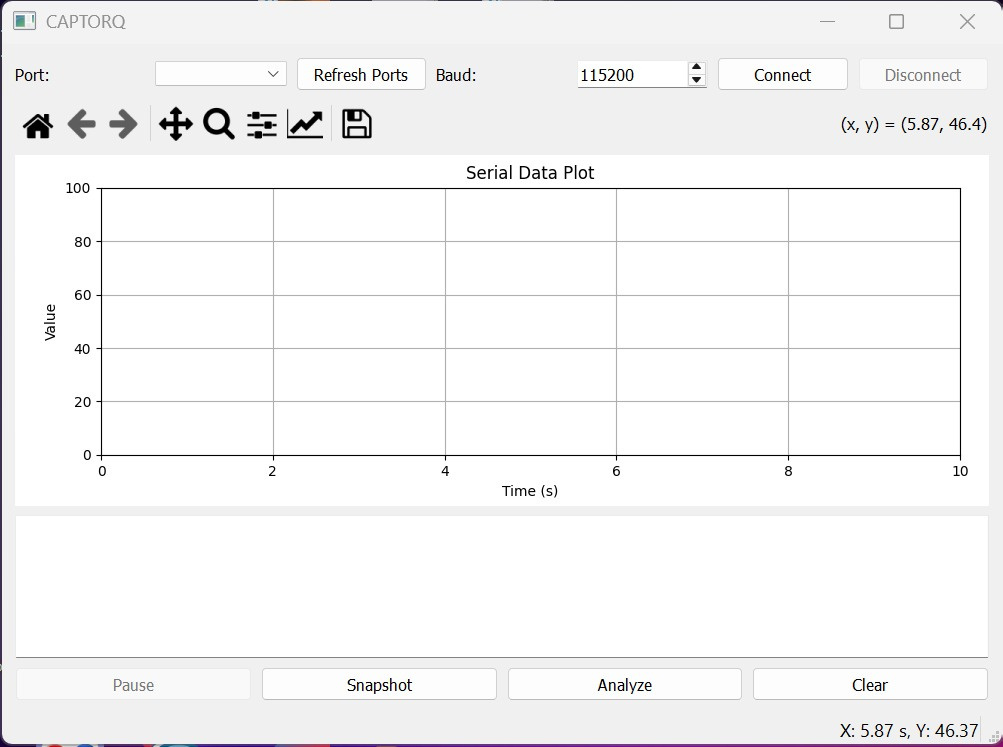
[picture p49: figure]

Step 4: Calibrate the Sensor (Optional but Recommended)

Enter calibration mode in the software.

Apply known torque and note the output.

Adjust settings for accurate measurement (gain, offset).

Get the coefficient by polynomial curve fitting. Upload the coefficients to the microcontroller through USB.

Step 5: Final Testing

Apply torque and check if real-time values are displayed.

Verify stable, consistent readings.

Ensure all mechanical and electrical parts are secure.

## 04. Maintenance

### 4.1 Preventive Maintenance

Manpower: One technician.
Tools & Equipment: Multimeter, torque calibrator software.

Procedure:

1.Inspect enclosure and shaft weekly: Visually check the enclosure for cracks, dust accumulation, or signs of wear. Examine the shaft for misalignment, corrosion, or physical damage.
2.Check USB and connection integrity: Inspect the USB cable for fraying, bends, or loose connectors. Test the connection by plugging/unplugging and ensuring a secure fit.
3.Clean sensor with non-corrosive cloth: Refer to section 4.3
4.Calibrate monthly: Connect the torque calibrator software to the MCU via USB. Apply a known torque using a torque reference standard. Adjust the capacitance-to-digital converter settings based on the software’s calibration prompts.

### 4.2 Troubleshooting

Problem | Possible Cause | Solution
Not powering on | No power, faulty cable | Check 5V source and USB
Inaccurate reading | Misalignment | Realign plates
Noise in signal | EMI form environment | Use shielded USB cables
Flat output | No torque / sensor damaged | Check load, inspect plates, Test the cable, see if LED light is visible through the USB opening
Drift in readings | Temperature variations, aging components | Implement temperature compensation, periodic recalibration
Zero offset error | Mechanical preload, residual stress | Perform zero calibration with no load, check mounting for stress
Unstable readings | Mechanical vibration or loose aseembly | Secire sensor mounting, dampen vibrations, tighten screws
Sensor overheating | Short circuit or overcurrent from USB supply | Check for shorts, ensure proper current draw, add protection circuitry
USB not recognized | Fault USB cable or damaged USB connector | Try a different cable, inspect and clean USB port, check USB connector soldering

WARNING:
To minimize risks and ensure safe operation, it is critical to follow current safety standards during the planning, configuration, installation, and use of the capacitive torque sensor.

CAUTION:
Operate the capacitive torque sensor with extreme care. The sensor is a high-precision and sensitive device and can suffer irreversible damage from: Mechanical shock (e.g., dropping or striking),
Chemical exposure (e.g., acids or solvents),
Thermal stress (e.g., exposure to hot air, steam, or extreme temperature changes).

QUALIFIED PERSONNEL

Installation, handling, and operation of the capacitive torque sensor must only be performed by qualified personnel who have:

Read and understood the full user manual,
Paid particular attention to all safety warnings and technical requirements.

### 4.3 Cleaning

Follow these steps for cleaning the torque sensor to ensure continued proper operation.

1.Power off the system and disconnect it from the USB.
2.Gently wipe the sensor plates with a non-corrosive, lint-free cloth to remove dust or debris.
3.Use compressed air and a small brush to clear hard-to-reach areas, avoiding excessive pressure.
4.Ensure no moisture or residue remains on the sensor surfaces.

### 4.4 Safety precautions

NOTICE

To ensure safe and reliable operation:

1.Periodically inspect all electrical and mechanical connections.
2.Always wear protective eyewear when working near rotating machinery. 3.Never wear loose clothing or neckties near rotating components.
4.Do not stand too close or lean over any rotating shafts or drive chains.

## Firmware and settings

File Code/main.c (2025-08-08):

#define F_CPU 16000000UL
#include <avr/io.h>
#include <util/delay.h>
#include <stdio.h>
#include "m_usb.h"

// SPI Pin Definitions for ATmega32U4
#define SPI_DDR  DDRB
#define SPI_PORT PORTB
#define MOSI     PB2
#define MISO     PB3
#define SCK      PB1
#define SS       PB0 // Slave Select pin for PCAP04

// PCAP04 SPI Commands
#define OPCODE_WRITE_CFG    0xA3
#define OPCODE_READ_CFG     0x23
#define OPCODE_READ_RES     0x40  // plus address
#define OPCODE_POR          0x88
#define OPCODE_INIT         0x8A
#define OPCODE_CDC_START    0x8C
#define OPCODE_TEST_READ    0x7E
#define WR_MEM 		0xA0
#define RD_MEM 		0x20
#define DSP_TRIG 0x8D


// Standard Firmware, <PCap04_standard_v1.hex>, Bytewise
// 34 Rows x 16 Bytes  +  1 Rows x 4 Bytes  = 548 Bytes
uint8_t standard_fw[548] = {
	0x24, 0x05, 0xA0, 0x01, 0x20, 0x55, 0x42, 0x5C, 0x48, 0xB1, 0x07, 0x92, 0x02, 0x20, 0x13, 0x02,
	0x20, 0x93, 0x02, 0xB2, 0x02, 0x78, 0x20, 0x54, 0xB3, 0x06, 0x91, 0x00, 0x7F, 0x20, 0x86, 0x20,
	0x54, 0xB6, 0x03, 0x72, 0x62, 0x20, 0x54, 0xB7, 0x00, 0x00, 0x42, 0x5C, 0xA1, 0x00, 0x49, 0xB0,
	0x00, 0x49, 0x40, 0xAB, 0x5D, 0x92, 0x1C, 0x90, 0x02, 0x7F, 0x20, 0x86, 0x66, 0x67, 0x76, 0x77,
	0x66, 0x7A, 0xCF, 0xCD, 0xE6, 0x43, 0xF1, 0x44, 0x29, 0xE0, 0x7A, 0xDC, 0xE7, 0x41, 0x32, 0xAA,
	0x01, 0x99, 0xFD, 0x7B, 0x01, 0x7A, 0xCF, 0xEB, 0xE6, 0x43, 0xF1, 0x44, 0x29, 0xE0, 0x7A, 0xC1,
	0xE7, 0x41, 0x32, 0x6A, 0xDE, 0x44, 0x7A, 0xCF, 0xEA, 0xE6, 0x43, 0xF1, 0x44, 0x29, 0xE0, 0x6A,
	0xDF, 0x44, 0x7A, 0xC4, 0xE7, 0x41, 0x32, 0xAB, 0x05, 0x7A, 0xC1, 0xE1, 0x43, 0xE0, 0x3A, 0x7A,
	0xC0, 0xE1, 0x43, 0xE0, 0x3A, 0x02, 0x7A, 0xCF, 0xE6, 0xE6, 0x43, 0xF1, 0x44, 0x29, 0xE0, 0x7A,
	0xEF, 0x44, 0x02, 0x20, 0x9D, 0x84, 0x01, 0x21, 0x2E, 0x21, 0x74, 0x20, 0x37, 0xC8, 0x7A, 0xE7,
	0x43, 0x49, 0x11, 0x6A, 0xD4, 0x44, 0x7A, 0xC1, 0xD8, 0xE6, 0x43, 0xE9, 0x44, 0x1C, 0x43, 0x13,
	0xAB, 0x63, 0x6A, 0xDE, 0x41, 0xAB, 0x0B, 0x46, 0x46, 0x46, 0x7A, 0xDF, 0xFF, 0xFF, 0xFF, 0xFF,
	0xE3, 0x41, 0x32, 0x1C, 0x44, 0xE9, 0x13, 0x6A, 0xD4, 0x13, 0x41, 0xAA, 0xDF, 0x7A, 0xC5, 0xE1,
	0x43, 0x49, 0xE0, 0x34, 0x7A, 0xCF, 0xE3, 0xE6, 0x43, 0xF1, 0x44, 0x29, 0xE0, 0xDB, 0xC0, 0x27,
	0xE5, 0x6A, 0xDF, 0x43, 0x7A, 0xC8, 0xE7, 0x41, 0x30, 0xAB, 0x03, 0x86, 0x01, 0x92, 0x37, 0x7A,
	0xC6, 0xE7, 0x41, 0x7A, 0xFA, 0xE7, 0x43, 0xEA, 0x44, 0x7A, 0xC1, 0xE1, 0xE6, 0x43, 0xE9, 0x44,
	0x25, 0xE0, 0x7A, 0xC6, 0xE7, 0x41, 0x7A, 0xFA, 0xE7, 0x43, 0xEA, 0x44, 0x7A, 0xC0, 0xE7, 0x43,
	0xE9, 0x44, 0x25, 0xE0, 0x92, 0x10, 0x7A, 0xE1, 0x44, 0xE2, 0x44, 0xE3, 0x44, 0xE4, 0x44, 0xE5,
	0x44, 0xE6, 0x44, 0xE7, 0x44, 0xE8, 0x44, 0xC1, 0xD8, 0x24, 0x3E, 0x92, 0xFF, 0x02, 0x7A, 0xCF,
	0xD7, 0xE6, 0x43, 0xF1, 0x44, 0x7A, 0xD0, 0xE7, 0x43, 0x2A, 0x2A, 0x32, 0xAB, 0x03, 0x42, 0x5C,
	0x92, 0x03, 0x7A, 0xC0, 0xE1, 0x43, 0xD9, 0x27, 0x90, 0x6A, 0xDF, 0x43, 0x7A, 0xC8, 0xE7, 0x41,
	0x32, 0xAB, 0x03, 0x86, 0x01, 0x92, 0x11, 0x7A, 0xC2, 0x43, 0x7A, 0xE7, 0x44, 0x6A, 0xC6, 0x44,
	0x7A, 0xC3, 0x43, 0x7A, 0xE8, 0x44, 0x6A, 0xC7, 0x44, 0xC1, 0xD4, 0x24, 0x57, 0x7A, 0xC8, 0xE1,
	0x43, 0xE0, 0x3A, 0x02, 0x7A, 0xCF, 0xE7, 0xE6, 0x43, 0xF1, 0x44, 0x29, 0xE0, 0x7A, 0xC7, 0xE1,
	0x41, 0x6A, 0xD4, 0x45, 0x5A, 0x25, 0x36, 0x46, 0x46, 0x46, 0x46, 0x7A, 0xE9, 0x44, 0x7A, 0xC0,
	0xE7, 0x43, 0x55, 0x7A, 0xEA, 0x45, 0x7A, 0xE9, 0x51, 0x1C, 0x43, 0x6A, 0xCA, 0x44, 0x1D, 0x43,
	0x6A, 0xCB, 0x44, 0x7A, 0xC1, 0xCA, 0xE6, 0x43, 0xE9, 0x44, 0x7A, 0xC1, 0xE1, 0x43, 0x7A, 0xCC,
	0xE0, 0xE6, 0x41, 0x2C, 0x42, 0x7A, 0xC5, 0xE1, 0x43, 0x49, 0xE0, 0x34, 0x7A, 0xC1, 0xCC, 0xE6,
	0x43, 0xE9, 0x44, 0x7A, 0xC1, 0xE1, 0x43, 0x2C, 0x70, 0x7A, 0xCC, 0x43, 0x7A, 0xCF, 0x44, 0x7A,
	0xCD, 0x43, 0x7A, 0xCE, 0x44, 0x6A, 0xCA, 0x43, 0xC1, 0xCA, 0x7A, 0xE6, 0x41, 0xE9, 0x45, 0x2B,
	0xAE, 0xEE, 0x44, 0x7A, 0xC1, 0xCA, 0xE6, 0x43, 0xE9, 0x44, 0x7A, 0xC1, 0xE1, 0x43, 0x7A, 0xCC,
	0xEC, 0xE6, 0x41, 0x2C, 0x42, 0x7A, 0xC5, 0xE1, 0x43, 0x49, 0xE0, 0x34, 0x7A, 0xC1, 0xCC, 0xE6,
	0x43, 0xE9, 0x44, 0x7A, 0xC1, 0xE1, 0x43, 0x2C, 0x70, 0x7A, 0xCC, 0x43, 0x7A, 0xCF, 0x44, 0x7A,
	0xCD, 0x43, 0x7A, 0xCE, 0x44, 0x6A, 0xCB, 0x43, 0xC1, 0xCA, 0x7A, 0xE6, 0x41, 0xE9, 0x45, 0x2B,
	0xAE, 0xED, 0x44, 0x02
};

// Initialize SPI in Master Mode
void SPI_Init(void)
{
	// Set MOSI, SCK, SS as output; MISO as input
	SPI_DDR |= (1 << MOSI) | (1 << SCK) | (1 << SS);
	SPI_DDR &= ~(1 << MISO);
	
	// Set SS high initially
	SPI_PORT |= (1 << SS);
	
	// Enable SPI, Master, CPOL=0, CPHA=1 (SPI Mode 1), fosc/16
	SPCR = (1 << SPE) | (1 << MSTR) | (1 << CPHA) | (1 << SPR0);
}

// SPI transfer: send and receive one byte
uint8_t SPI_Transfer(uint8_t data)
{
	SPDR = data;
	while (!(SPSR & (1 << SPIF)));
	return SPDR;
}
// Function Prototypes
void SPI_Init(void);
uint8_t SPI_Transfer(uint8_t data);
void PCAP04_WriteRegister(uint8_t address, uint8_t data);
uint8_t PCAP04_ReadRegister(uint8_t address);
void PCAP04_Init(void);
void PCAP04_CDC_START(void);

// Write: send OPCODE_WRITE + address + data
void PCAP04_WriteRegister(uint8_t address, uint8_t data)
{
	SPI_PORT &= ~(1 << SS); // SS low
	_delay_ms(1);           // setup time
	
	SPI_Transfer(OPCODE_WRITE_CFG); // send write opcode
	SPI_Transfer(address | 0xC0);      // send target address
	SPI_Transfer(data);        // send data
	
	_delay_ms(1);           // hold time
	SPI_PORT |= (1 << SS); // SS high
	_delay_ms(1);
}

// Read: send OPCODE_READ + address, then read response
uint8_t PCAP04_ReadRegister(uint8_t address)
{
	uint8_t val;
	SPI_PORT &= ~(1 << SS); // SS low
	_delay_ms(1);           // setup time
	
	SPI_Transfer(OPCODE_READ_CFG); // send read opcode
	SPI_Transfer(address | 0xC0);     // send target address
	val = SPI_Transfer(0x00); // read response
	
	_delay_ms(1);           // hold time
	SPI_PORT |= (1 << SS); // SS high
	_delay_ms(1);
	return val;
}

uint8_t PCAP04_TestRead(void) {
	uint8_t val;
	SPI_PORT &= ~(1 << SS);
	_delay_ms(1);
	SPI_Transfer(OPCODE_TEST_READ);  // send test read opcode
	val = SPI_Transfer(0x00);        // get response
	_delay_ms(1);
	SPI_PORT |= (1 << SS);
	_delay_ms(1);
	return val;
}

void Write_Byte_Auto_Incr(uint8_t opcode, uint8_t address, const uint8_t* byte_array, int length)
{
	// Pull SS low to start SPI transaction
	SPI_PORT &= ~(1 << SS);
	_delay_ms(1);

	// Transmit opcode (2 bytes)

	SPI_Transfer(opcode);
	SPI_Transfer(address);

	// Send data sequentially
	for (int i = 0; i < length; i++) {

		SPI_Transfer(byte_array[i]);
		_delay_ms(5);
	}

	_delay_ms(10);
	SPI_PORT |= (1 << SS); // End transaction
	_delay_ms(1);
}

void Read_Byte_Auto_Incr(uint8_t opcode, uint8_t address, int length)
{

	uint8_t val=0;
	// Pull SS low to start SPI transaction
	SPI_PORT &= ~(1 << SS);
	_delay_ms(1);

	// Transmit opcode (2 bytes)

	SPI_Transfer(opcode);
	SPI_Transfer(address);
	for (int i = 0; i < length; i++) {
		val=SPI_Transfer(0x00);

	}


	SPI_PORT |= (1 << SS); // End transaction
	_delay_ms(1);
	
}
// Initialize PCAP04: example config
void PCAP04_CDC_START(void)
{
	// For example, write to config register 0x00
	SPI_PORT &= ~(1 << SS); // SS low
	_delay_ms(1);           // setup time
	
	SPI_Transfer(OPCODE_CDC_START); // send write opcode
	_delay_ms(1);           // hold time
	SPI_PORT |= (1 << SS); // SS high
	_delay_ms(1);
}

void DSP_TRIG_ACTION(void)
{
	// For example, write to config register 0x00
	SPI_PORT &= ~(1 << SS); // SS low
	_delay_ms(1);           // setup time
	
	SPI_Transfer(DSP_TRIG); // send write opcode
	_delay_ms(1);           // hold time
	SPI_PORT |= (1 << SS); // SS high
	_delay_ms(1);
}


void PCAP04_Init(void) {
	SPI_PORT &= ~(1 << SS); // SS low
	_delay_ms(1);           // setup time
	
	SPI_Transfer(OPCODE_INIT); // send write opcode
	_delay_ms(1);           // hold time
	SPI_PORT |= (1 << SS); // SS high
	_delay_ms(1);
	PCAP04_WriteRegister(0x00, 0x01); // Set Oscillator Frequency to 50 kHz
	PCAP04_WriteRegister(0x04, 0b10010001); // CFG4: grounded sensor  + C_REF_INT
	PCAP04_WriteRegister(0x06, 0x3F); // CFG6: Enable PC0
	PCAP04_WriteRegister(0x07, 0x08); // CFG7: averaging = 8
	PCAP04_WriteRegister(0x08, 0x00); // CFG8: high byte of averaging
	PCAP04_WriteRegister(0x09, 0x19); // CFG9–11: CONV_TIME for 1 kHz
	PCAP04_WriteRegister(0x0A, 0x00);
	PCAP04_WriteRegister(0x0B, 0x00);
	PCAP04_WriteRegister(0x12, 0x00); // CFG12: Offset compensation (default)
	PCAP04_WriteRegister(0x13, 0x01); // CFG19: CDC_START = 1 (continuous mode, Table 70)
	PCAP04_WriteRegister(0x1B, 0x08); // CFG27: DSP_SPEED = 2 (Recommended, Table 88)
	PCAP04_WriteRegister(0x22, 0xF0); // CFG34: DSP_TRIG_BG = 1 (Enabled, Section 7.6.3.7)
	uint8_t reg36 = PCAP04_ReadRegister(0x24); // CFG36
	reg36 &= ~(0xFF); // Clear all bits
	reg36 |= (1 << 3) | (1 << 1); // DSP_CONT_EN = 1, DSP_START = 1
	PCAP04_WriteRegister(0x24, reg36); // CFG36: DSP_CONT_EN=1, DSP_START=1, others 0
	PCAP04_WriteRegister(0x2F, 0x01); // CFG47: RUNBIT = 1
	uint8_t reg17 = PCAP04_ReadRegister(0x11); // Read existing value
	reg17 &= 0x03;                       // Clear bits 6:2 (keep bits 1:0)
	reg17 |= (7 << 2);                  // Set C_REF_SEL = 7 (approx. 10 pF internal reference)
	PCAP04_WriteRegister(0x11, reg17);        // Write back updated value
}



uint32_t PCAP04_ReadResult(uint8_t address)
{
	uint32_t val = 0;
	SPI_PORT &= ~(1 << SS); // SS low
	_delay_ms(1);           // setup time
	
	SPI_Transfer(OPCODE_READ_RES | address); // Send read result opcode with address (0x40 + address)
	uint8_t byte1 = SPI_Transfer(0x00);  // MSB
	uint8_t byte2 = SPI_Transfer(0x00);
	uint8_t byte3 = SPI_Transfer(0x00);
	uint8_t byte4 = SPI_Transfer(0x00);
	
	
	val = ((uint32_t)byte1 << 24) | ((uint32_t)byte2 << 16) | ((uint32_t)byte3 << 8) | ((uint32_t)byte4);



	
	_delay_ms(1);           // hold time
	SPI_PORT |= (1 << SS); // SS high
	_delay_ms(1);
	return val;
}

float binaryFractionToDecimal(uint8_t frac_bits, uint8_t num_bits) {
	float result = 0.0;
	// Loop through each bit
	for (uint8_t i = 0; i < num_bits; i++) {
		// Check if bit is set
		if (frac_bits & (1 << (num_bits - 1 - i))) {
			// Add corresponding fractional value 2^-(i+1)
			result += 1.0f / (1 << (i + 1));
		}
	}
	return result;
}




// Main function
int main(void) {
	uint32_t result;
	m_usb_init();
	_delay_ms(1);
	SPI_Init();
	_delay_ms(1);
	PCAP04_Init();
	_delay_ms(1);

	Write_Byte_Auto_Incr(WR_MEM, 0x00, standard_fw, 548);
	_delay_ms(10);
	Read_Byte_Auto_Incr(RD_MEM, 0X00, 10);
	_delay_ms(10);
	PCAP04_WriteRegister(0x2F, 0x01); // CFG47: RUNBIT = 1
	_delay_ms(10);
	PCAP04_CDC_START();
	_delay_ms(20);
	
	while (1) {
		DSP_TRIG_ACTION();
        result = PCAP04_ReadResult(0x00); // 0x00 is the address for Res0
		//m_usb_tx_uint(result);         
		//m_usb_tx_push();
		_delay_ms(10);
		

		uint8_t int_part = (result >> 27) & 0x1F;           // Extract top 5 bits
		
		//unsigned int decimal_value=0;
		//decimal_value = (unsigned int)strtol(int_part, NULL, 16);



		uint32_t frac_raw = result & 0x07FFFFFF;            // Extract lower 27 bits
		float fraction_value = binaryFractionToDecimal(frac_raw, 16);
	
		//m_usb_tx_long(decimal_value);
		//m_usb_tx_string(".");
		m_usb_tx_long(fraction_value);
		m_usb_tx_push();
		_delay_ms(1);
		m_usb_tx_string("\n");
		m_usb_tx_push();
		_delay_ms(1);
		
		 
	}
}

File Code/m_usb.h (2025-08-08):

// -----------------------------------------------------------------------------
// AVR USB communication subsystem for ATmega32u4
// version: 2.2
// same as version 2.1 built for M2 MAEVARM
// date: June 16, 2012
// authors: J. Fiene & J. Romano
// -----------------------------------------------------------------------------

#ifndef m_usb__
#define m_usb__

#include <avr/io.h>
#include <avr/interrupt.h>
#include <avr/pgmspace.h>
#include <stdlib.h>


// -----------------------------------------------------------------------------
// Public functions:
// -----------------------------------------------------------------------------

// INITIALIZATION: -------------------------------------------------------------

void m_usb_init(void);
// initialize the USB subsystem

char m_usb_isconnected(void);
// confirm that the USB port is connected to a PC


// RECEIVE: -------------------------------------------------------------------

unsigned char m_usb_rx_available(void);
// returns the number of bytes (up to 255) waiting in the receive FIFO buffer

char m_usb_rx_char(void);
// retrieve a oldest byte from the receive FIFO buffer (-1 if timeout/error)

void m_usb_rx_flush(void);
// discard all data in the receive buffer



// TRANSMIT: ------------------------------------------------------------------

char m_usb_tx_char(unsigned char c);
// add a single 8-bit unsigned char to the transmit buffer, return -1 if error

void m_usb_tx_hexchar(unsigned char i);
// add an unsigned char to the transmit buffer, send as two hex-value characters

void m_usb_tx_hex(unsigned int i);
// add an unsigned int to the transmit buffer, send as four hex-value characters

void m_usb_tx_int(int i);
// add a signed int to the transmit buffer, send as a sign character then 5 decimal-value characters

void m_usb_tx_uint(unsigned int i);
// add an unsigned int to the transmit buffer, send as 5 decimal-value characters

void m_usb_tx_long(long i);
// add a signed long to the transmit buffer, send as a sign character then 5 decimal-value characters

void m_usb_tx_ulong(unsigned long i);
// add an unsigned long to the transmit buffer, send as 5 decimal-value characters

#define m_usb_tx_string(s) print_P(PSTR(s))
// add a string to the transmit buffer



// -----------------------------------------------------------------------------
// -----------------------------------------------------------------------------
// -----------------------------------------------------------------------------

// ---- OVERLOADS FOR M1 BACK COMPATIBILITY ----
#define usb_init()			m_usb_init()
#define usb_configured()	m_usb_isconnected()

#define usb_rx_available()	m_usb_rx_available()
#define usb_rx_flush()		m_usb_rx_flush()
#define usb_rx_char()		m_usb_rx_char()

#define usb_tx_char(val)	m_usb_tx_char(val)
#define usb_tx_hex(val)		m_usb_tx_hex(val)
#define usb_tx_decimal(val)	m_usb_tx_uint(val)
#define usb_tx_string(val)	m_usb_tx_string(val)
#define usb_tx_push()		m_usb_tx_push()

#define m_usb_rx_ascii()	m_usb_rx_char()
#define m_usb_tx_ascii(val)	m_usb_tx_char(val)


// EVERYTHING ELSE *****************************************************************

// setup

int8_t usb_serial_putchar(uint8_t c);	// transmit a character
int8_t usb_serial_putchar_nowait(uint8_t c);  // transmit a character, do not wait
int8_t usb_serial_write(const uint8_t *buffer, uint16_t size); // transmit a buffer
void print_P(const char *s);
void phex(unsigned char c);
void phex16(unsigned int i);
void m_usb_tx_hex8(unsigned char i);
void m_usb_tx_push(void);


// serial parameters
uint32_t usb_serial_get_baud(void);	// get the baud rate
uint8_t usb_serial_get_stopbits(void);	// get the number of stop bits
uint8_t usb_serial_get_paritytype(void);// get the parity type
uint8_t usb_serial_get_numbits(void);	// get the number of data bits
uint8_t usb_serial_get_control(void);	// get the RTS and DTR signal state
int8_t usb_serial_set_control(uint8_t signals); // set DSR, DCD, RI, etc

// constants corresponding to the various serial parameters
#define USB_SERIAL_DTR			0x01
#define USB_SERIAL_RTS			0x02
#define USB_SERIAL_1_STOP		0
#define USB_SERIAL_1_5_STOP		1
#define USB_SERIAL_2_STOP		2
#define USB_SERIAL_PARITY_NONE		0
#define USB_SERIAL_PARITY_ODD		1
#define USB_SERIAL_PARITY_EVEN		2
#define USB_SERIAL_PARITY_MARK		3
#define USB_SERIAL_PARITY_SPACE		4
#define USB_SERIAL_DCD			0x01
#define USB_SERIAL_DSR			0x02
#define USB_SERIAL_BREAK		0x04
#define USB_SERIAL_RI			0x08
#define USB_SERIAL_FRAME_ERR		0x10
#define USB_SERIAL_PARITY_ERR		0x20
#define USB_SERIAL_OVERRUN_ERR		0x40

// This file does not include the HID debug functions, so these empty
// macros replace them with nothing, so users can compile code that
// has calls to these functions.
#define usb_debug_putchar(c)
#define usb_debug_flush_output()

#define EP_TYPE_CONTROL			0x00
#define EP_TYPE_BULK_IN			0x81
#define EP_TYPE_BULK_OUT		0x80
#define EP_TYPE_INTERRUPT_IN		0xC1
#define EP_TYPE_INTERRUPT_OUT		0xC0
#define EP_TYPE_ISOCHRONOUS_IN		0x41
#define EP_TYPE_ISOCHRONOUS_OUT		0x40
#define EP_SINGLE_BUFFER		0x02
#define EP_DOUBLE_BUFFER		0x06
#define EP_SIZE(s)	((s) == 64 ? 0x30 :	\
((s) == 32 ? 0x20 :	\
((s) == 16 ? 0x10 :	\
0x00)))

#define MAX_ENDPOINT		4

#define LSB(n) (n & 255)
#define MSB(n) ((n >> 8) & 255)

#define HW_CONFIG() (UHWCON = 0x01)

#ifdef M1
#define PLL_CONFIG() (PLLCSR = 0x02) // fixed to 8MHz clock
#else
#define PLL_CONFIG() (PLLCSR = 0x12) // 0001 0010 For a 16MHz clock
#endif

#define USB_CONFIG() (USBCON = ((1<<USBE)|(1<<OTGPADE)))
#define USB_FREEZE() (USBCON = ((1<<USBE)|(1<<FRZCLK)))

// standard control endpoint request types
#define GET_STATUS			0
#define CLEAR_FEATURE			1
#define SET_FEATURE			3
#define SET_ADDRESS			5
#define GET_DESCRIPTOR			6
#define GET_CONFIGURATION		8
#define SET_CONFIGURATION		9
#define GET_INTERFACE			10
#define SET_INTERFACE			11
// HID (human interface device)
#define HID_GET_REPORT			1
#define HID_GET_PROTOCOL		3
#define HID_SET_REPORT			9
#define HID_SET_IDLE			10
#define HID_SET_PROTOCOL		11
// CDC (communication class device)
#define CDC_SET_LINE_CODING		0x20
#define CDC_GET_LINE_CODING		0x21
#define CDC_SET_CONTROL_LINE_STATE	0x22

#endif
